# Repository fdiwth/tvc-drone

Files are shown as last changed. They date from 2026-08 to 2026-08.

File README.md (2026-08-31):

# About

<div align="center">
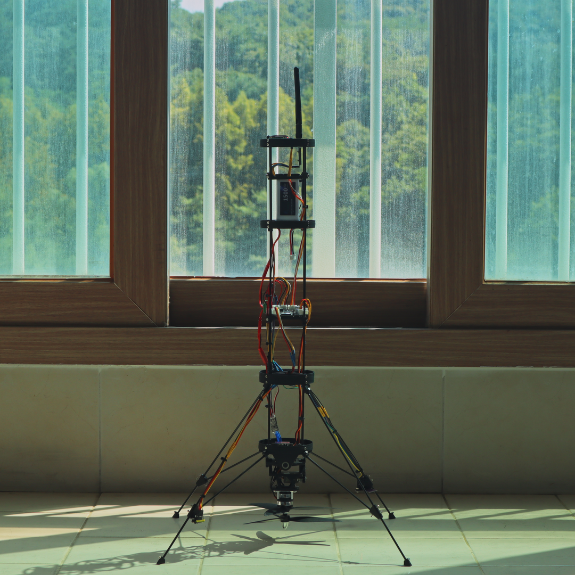
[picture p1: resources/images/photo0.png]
	
</div>

The TVC(Thrust Vector Control) drone project is a demonstration of the control capabilities that can be achieved in amateur rocketry. Similar to an actual rocket with a TVC system, the drone is capable of balancing and angling itself at desired a desired set-point by vectoring the thrust it produces appropriately. This repository contains the documentation of the project along with sources of both hardware and software that was developed in the duration of the project.

# Navigating the Repository

The repository is mainly split into five sections:

 - tvc-drone/apps
 - tvc-drone/docs
 - tvc-drone/gcs-firmware
 - tvc-drone/drone-firmware
 - tvc-drone/resources

The best way to navigate this repository if you are looking for an in depth guide is to follow along the documentation available in your language of choice below tvc-drone/docs. The documentation explains the design choices, and the links to appropriate sections of the repository.

If you are looking to look at a specific part of the sources, navigating to the appropriately named folders will help find the resources you need.

To get a short overview of the features used in the project, check out the overview section available at tvc-drone/docs/{language}.

# Videos

Click on the images of videos to watch them. Watch video 5 or 6 if you want to see the result.

<div align="center">
	<a href="https://www.instagram.com/reel/DbS7qK0ilDo/?utm_source=ig_web_copy_link&igsi=MzRlODBiNWFlZA==" target="_blank" rel="noopener noreferrer"> 
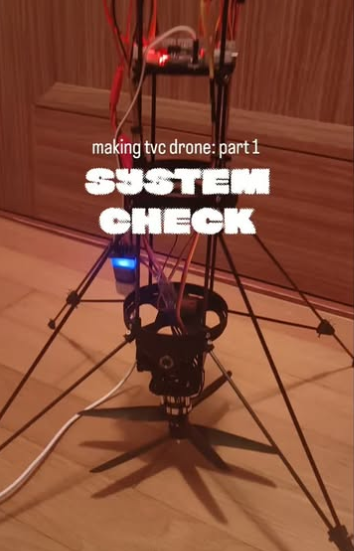
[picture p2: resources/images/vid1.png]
		
	</a>
	<a href="https://www.instagram.com/reel/DbS74EgiR94/?utm_source=ig_web_copy_link&igsi=MzRlODBiNWFlZA==" target="_blank" rel="noopener noreferrer"> 
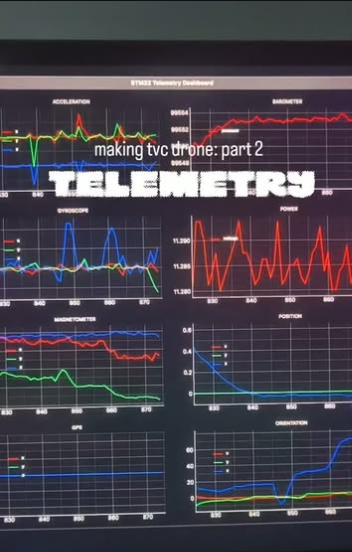
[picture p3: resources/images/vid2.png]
		
	</a>
	<a href="https://www.instagram.com/reel/DbS8F_3iFV1/?utm_source=ig_web_copy_link&igsi=MzRlODBiNWFlZA==" target="_blank" rel="noopener noreferrer"> 
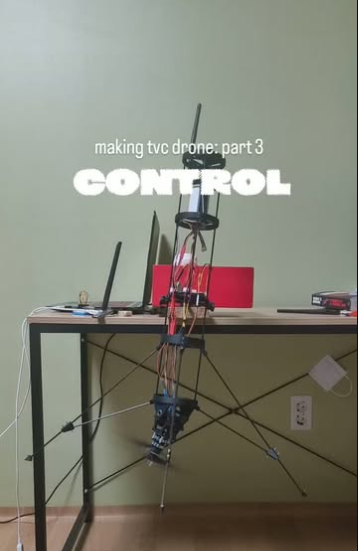
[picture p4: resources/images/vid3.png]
		
	</a>
	<a href="https://www.instagram.com/reel/DbS8Rr6iW9l/?utm_source=ig_web_copy_link&igsi=MzRlODBiNWFlZA==" target="_blank" rel="noopener noreferrer"> 
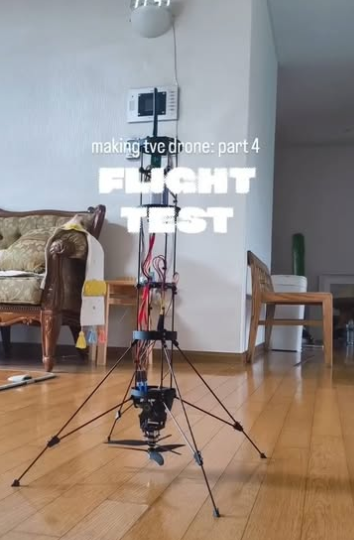
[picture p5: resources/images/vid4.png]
		
	</a>
	<a href="https://www.instagram.com/reel/Db1qBOZSPOG/?utm_source=ig_web_copy_link&igsi=MzRlODBiNWFlZA==" target="_blank" rel="noopener noreferrer"> 
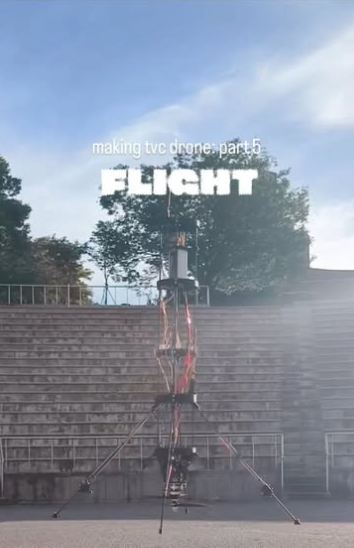
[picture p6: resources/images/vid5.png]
		
	</a>
	<a href="https://www.instagram.com/reel/Db5uuldi-zH/?utm_source=ig_web_copy_link&igsi=MzRlODBiNWFlZA==" target="_blank" rel="noopener noreferrer"> 
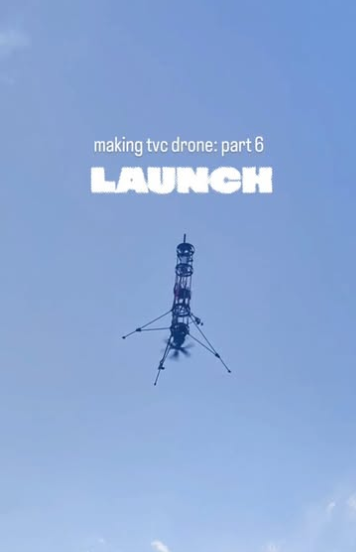
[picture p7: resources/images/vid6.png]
		
	</a>
</div>

# Disclaimer

This repository is merely a demonstration of what is achievable with a custom-built coaxial TVC drone stack, and is not a step-by-step guide on building one. Despite the project materials being open sourced, it is discouraged to use them directly in one's own project. However, anyone is welcome to use the documentations and source materials as a reference. But treat this as a reference point, not a direct dependency. 

# Contact

Anyone with any questions regarding this project are welcome to reach out through contact informations listed below.

instagram: fd.iwth
email: fdiwth@gmail.com

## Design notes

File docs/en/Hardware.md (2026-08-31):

# Index

1. [Design](#design)
	  - [Hardware Specifications](#hardware-specifications)
	  - [Coaxial Design](#coaxial-design)
	  - [Gimbal Design](#gimbal-design)
	  - [Body Design](#body-design)
	  - [Sensor Placement and Configuration](#sensor-placement-and-configuration)
2. [PCB](#pcb)
	  - [Component Overview](#component-overview)
	  - [System Initialization and Checks](#system-initialization-and-checks)
	  - [Microcontroller and Sensors](#microcontroller-and-sensors)
	  - [Data Logging Architecture](#data-logging-architecture)
	  - [Power System](#power-system)
	  - [Custom Sensor Modules](#custom-sensor-modules)
	  - [Power Delivery System](#power-delivery-system)

# Design

This section explains the hardware design of the drone along with why it was designed that way. Key hardware components and major design choices were made during the process of building, and each of them will be explained in the following sub-sections.

1. Hardware Specifications
2. Coaxial Design
3. Gimbal Design
4. Body Design

### **Hardware Specifications**

The drone uses the following core hardware components to achieve flight:
- **Motors**: DZP30 counter-rotating motors (KV: 1500, Thrust: ~280g each, Current: 0.5A at 11.1V).
- **ESCs**: XP-12A (12A rating, with BEC).
- **Propellers**: 7035 (7-inch diameter, 3.5-inch pitch, 3-blade, 5mm inner hole).
- **Battery**: 3S 1500mAh 45C LiPo with JST connector.

### **Coaxial Design**

Unlike a traditional rocket engine that doesn't produce any significant amount of z-axis torque, using a spinning motor with propellers introduces z-axis torque. The z-axis rotational dynamics are governed by two factors. A major dynamic at hand which is constantly present when the motors are spinning is the torque that is applied in the opposite direction of the spinning motor. This dynamic would not be present in a complete vacuum when the motor is not being either accelerated. Since there is no change in angular momentum without acceleration, there is effectively zero torque. However, in the real world, propellers attached to the motors create thrust by accelerating the air molecules which, according to Newton's third law of motion induces force in the opposite direction. This has the effect of decelerating the motors. In order to maintain a constant angular velocity, the motors need to accelerate, thus creating an equal and opposite torque on the body even when the motors are maintaining their angular velocity. Second, another dynamic at hand is the conservation of angular momentum. This can be seen when the motor accelerates by increasing/decreasing its angular velocity. 

For a drone to achieve stability it needs to be able to control it's z-axis. This is the reason for choosing the coaxial design. Having two motors rotating in the opposite direction allows the torque to cancel each other. In an ideal scenario, where both motors spin at the same angular velocity and produce equal amount of thrust(each of them producing 1/2 of total thrust) torques produced should have the same magnitude and be directed at opposite directions, making the net torque 0. However, real world is far from the ideal case. since two propellers are stacked on top of each other airflow from top propellers create iregullarties from the ideal scenario. Thus, we need to be able to control the angular velocity of each counter rotating motors individually. By accelerating one motor and decellerating the other appropriately, this system is capable of producing the same amount of thrust while creating a torque in the desired direction.

### **Gimbal Design**

The gimbal uses two cheap and widely available MG90S servos. Metal gear servos were particularly chosen because they have far less backlash than soft geared servos. The specific model was chosen because of its cheap price. 3D printed gears were used on both axis to reduce the amount of torque each motor has to generate and to allow the gimbal control to be more precise. However, the use of gears resulted in its own backlash problem, which had to be reduced by iteratively testing different gear diameters. 

In the design, one of the gears have a normal 3:1 reduction ratio, and the other has a 4:1 gear reduction ratio. This is due to the geometry of how the servos are mounted. Servo-x is operated like a normal gear with a gear ratio of 3:1 and has a fixed spinning axis, as shown in section analysis below.

<div align="center">
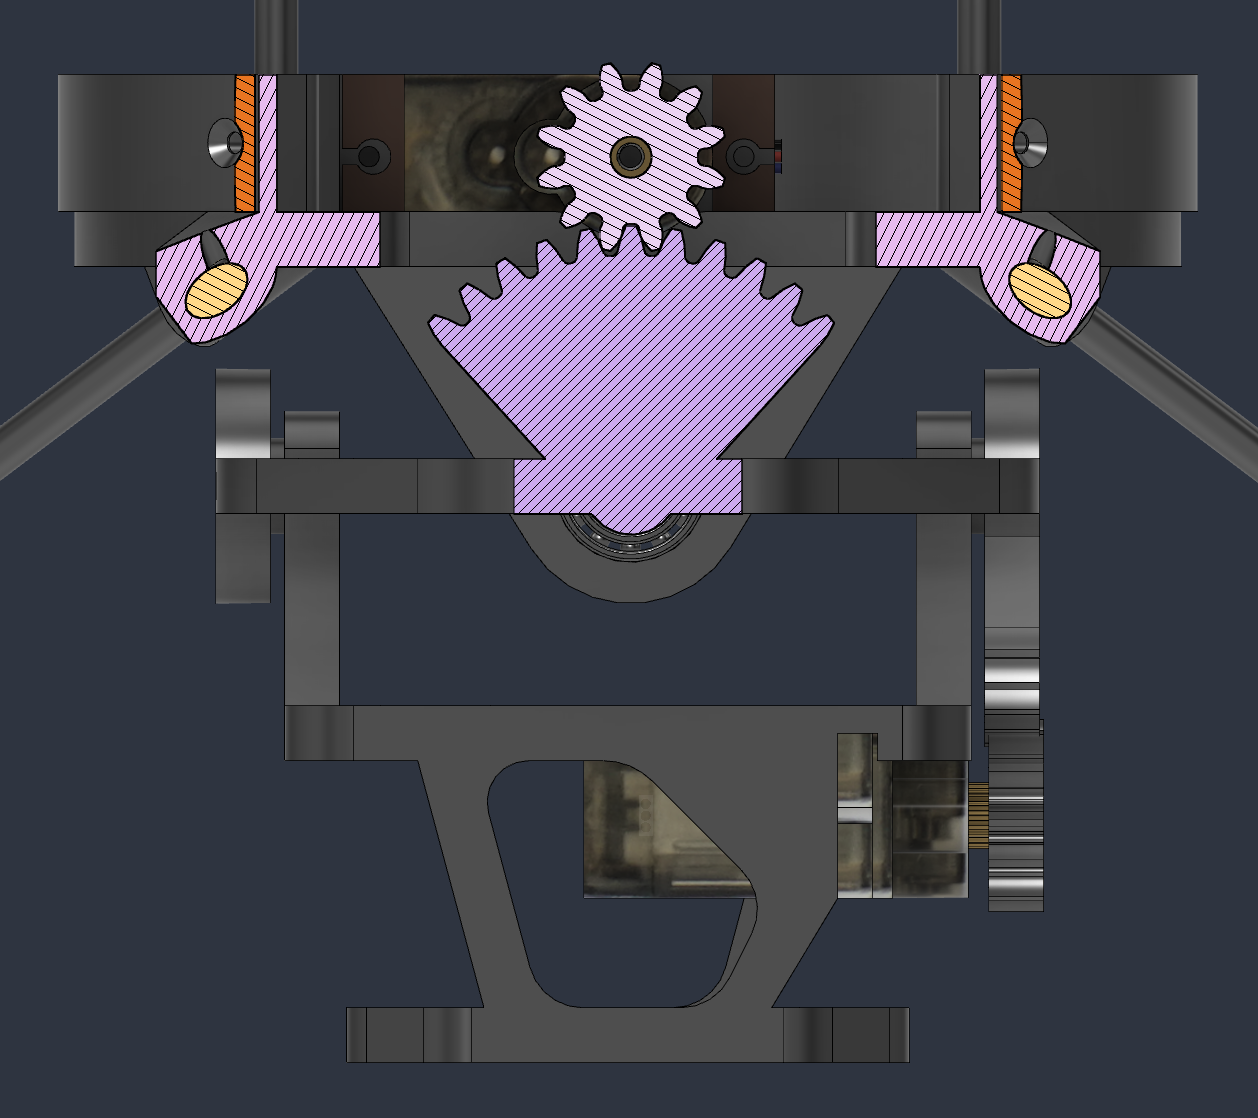
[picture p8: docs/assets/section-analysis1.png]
	
</div>

However, the gear attached to the servo-y revolves around the TVC axis as it rotates. This rotation of the axis makes it necessary for the servo to make an additional full rotation when TVC is rotated 360 degrees making the gear ratio 4:1. This effect has to be accounted for when managing TVC angles in software.

<div align="center">
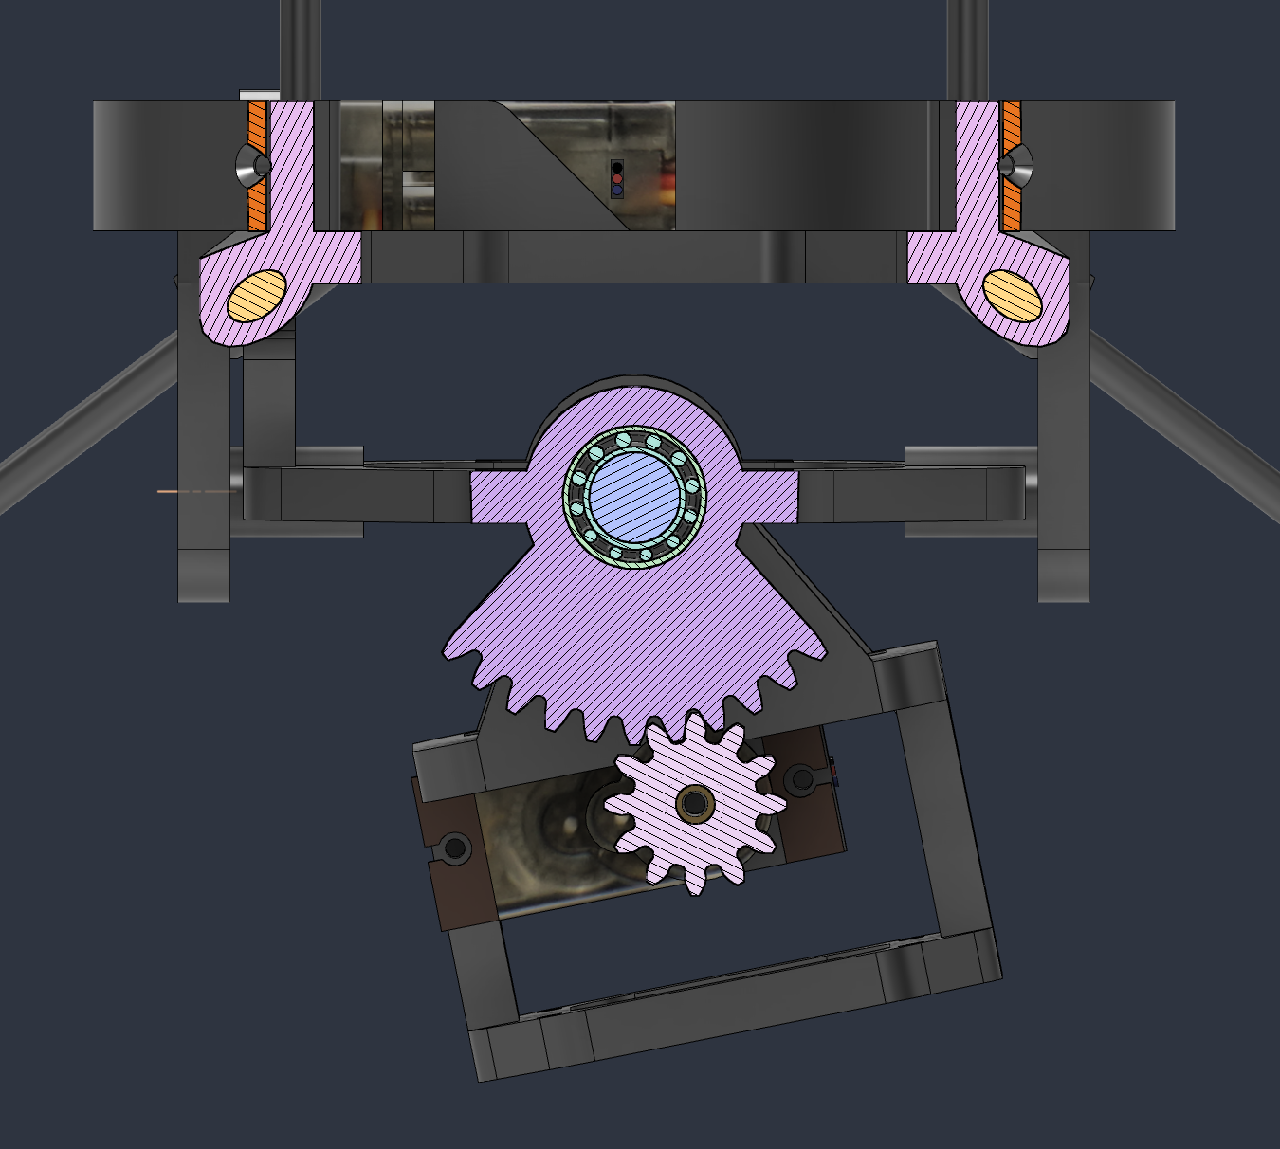
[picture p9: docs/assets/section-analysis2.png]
	
</div>

### **Body Design**

The body frame ware structured using 3mm solid carbon fiber rods cut to appropriate lengths to make the drone light weight and rigid. The rods are held together by custom designed 3D printed pieces. The rods are held to the 3D printed part by screws that was screwed into place by making the diameter of the hole in the 3D printed part slightly smaller than screw size. A small indent was made on the rod in the position of the screw, so that the indent would hold the rod in place.

The body was made to be long, and most of the mass(including the battery, motors, radio antenna) were located far from the center of mass intentionally! Since the moment of inertia is equivalent to 

$$I = \sum_{i=1}^{n} m_i r_i^2$$

where $r_i$ is the distance of small mass $m_i$ from the center of gravity, distributing the components with mass increases the moment of inertia of an object. Increased moment of inertia makes the tipping of the drone slower, since by definition moment of inertia is the resistance to change in angular velocity.

Other reasons for this design choice can be seen clearly with a simple example of the same 2D system with a proportional controller. Imagine a system that responds to an error by tilting the tvc gimbal proportionally to $\theta$(the error from desired angle of 0).

For small tvc deflection angle $\phi$,

$$ \tau = -F_t \cdot d \cdot \sin(\phi) \approx F_t \cdot d \cdot \phi$$
$$ I_{cg} \ddot \theta = -F_t \cdot d \cdot \phi$$

Since we are modeling a proportional controller,

$$\phi = K_p \theta$$
$$ I_{cg} \ddot \theta = -F_t \cdot d \cdot K_p \theta$$
$$  \ddot \theta + \frac {F_t \cdot d \cdot K_p}{I_{cg}} \theta = 0$$

This is similar to the equation of undamped harmonic oscillator which is written as
$\ddot x + \omega_n^2 x = 0$ where $\omega$ is the natural frequency of the system.

Thus, the closed loop natural frequency of this system can be expressed as

$$\omega_n = \sqrt{\frac {F_t \cdot d \cdot K_p}{I_{cg}}}$$

From this model, we can see that the closed-loop natural frequency increases as $I_{cg}$ decreases. A small $I_{cg}$ leads to rapid, high-frequency oscillations around the target angle. This is highly problematic for a real-world TVC drone because physical hardware constraints-such as a 50Hz servo refresh rate and non-zero servo transit time-are omitted from the ideal model. High frequencies paired with servo lag induce a catastrophic phase shift, leading to instability. By increasing $I_{cg}$, we effectively shift control authority from the chaotic, high-frequency raw rotational dynamics of a light airframe over to a tunable software parameter $K_{p}$. The enlarged $I_{cg}$ suppresses the natural frequency ceiling, allowing $K_{p}$ to be aggressively increased to reject wind disturbances heavily without forcing the servos past their physical bandwidth limitations.

### **Sensor Placement and Configuration**

Proper sensor placement and configuration are critical for accurate state estimation, particularly for sensors interacting directly with the ground.

- **IMU (ICM-42688-P)**: Configured in `main.c` for $\pm8$G acceleration and $\pm500$ degrees/sec, sampling at 1760Hz to minimize phase delay before filtering.
- **Barometer (BMP388)**: Configured to sample at 50Hz with 8$\times$ oversampling for pressure, balancing noise reduction with responsiveness.
- **Time of Flight (ToF) Sensor (VL53L1X)**: Placed facing directly downwards at one of the legs of the drone to measure altitude. The sensor is theoretically capable of measuring up to 4 meters, which perfectly aligns with the crucial low-altitude landing and hovering phases. 
- **Optical Flow Sensor (PMW3901)**: Mounted on one of the drone's outer legs located opposite of the leg ToF sensor is mounted to, due to space constraints and line-of-sight requirements. Because the leg mounts are angled, the sensor's native X and Y axes sit at a 45-degree angle relative to the flight controller's primary coordinate frame. To resolve this, the firmware mathematically rotates the raw PMW3901 readings by 45 degrees before fusing them into the velocity estimators.

# PCB

This section explains the architectural and hardware design choices behind the flight controller PCB, focusing on component selection and power delivery.

The PCB was designed using KiCAD, an open-source electronics design automation suite. The selection of components was crucial, as it dictates the capabilities, stability, and future extensibility of the TVC drone.

### **Component Overview**

| Type | Model | Interface | Purpose |
| --- | --- | --- | --- |
| MCU | STM32F722RET | SWD | Main flight controller processor |
| IMU | ICM-42688-P | SPI | 6-axis gyroscope and accelerometer |
| Magnetometer | BMM150 | I2C | Z-axis rotation and absolute heading |
| Barometer | BMP388 | SPI | Altitude and temperature sensing |
| GPS | U-blox NEO-7 | UART/Custom | Global Positioning System |
| Power Sensor | INA226 | I2C | Battery voltage and current monitoring  |
| Flash Memory | W25Q128JVSIQ | SPI | 16MB onboard flight data logging |
| SD card | TF-01A | SDMMC | Removable post-flight data storage |
| USB OTG | USB4105-GF-A-120 | USB-C | Debugging and data extraction |
| Power Mux | TPS2121 | - | Intelligent battery/USB power switching |
| Buzzer | MLT-8540 | GPIO | Audiovisual feedback |

### **System Initialization and Checks**

During boot, the flight controller executes `sys_init()` function to initialize the system. The function initializes all the components of the drone and tries to establish a connection with the GCS(Ground Control Station). 

A `sys_check()` function can also be run afterwards by sending "CHECK" command from the GCS. This ensures all sensors and components are functioning correctly before launch. The function includes:

1. **Audiovisual Feedback**: Testing the Buzzer and LEDs.
2. **Actuator Sweeps**: Commanding the X and Y servos, followed by the main motors, through a limited sweep to confirm ESC and servo responses.
3. **Sensor Polling**: Verifying the IMU (ICM-42688-P), Magnetometer (BMM150), Barometer (BMP388), and Power Sensor (INA226) are successfully responding to SPI/I2C DMA requests.
4. **Memory Verification**: Erasing and writing a test sector on the W25Q128 flash memory, and writing a mock CSV file to the SD card to ensure data logging will not fail mid-flight.

### **Microcontroller and Sensors**

The **MCU (Microcontroller Unit)** is responsible for running the attitude control loops, reading sensor data, and commanding the servos and motors. The STM32F722RET was chosen for its compact size, high clock speed, and rich set of hardware peripherals (SPI, I2C, SDMMC).

The **IMU (Inertial Measurement Unit)** provides the foundational gyroscope and accelerometer readings necessary for attitude stabilization. While the IMU accurately tracks X and Y axis rotations (pitch and roll), it cannot determine absolute Z-axis orientation (yaw) without drift. Therefore, a **Magnetometer (BMM150)** is included to sense the Earth's magnetic field and provide drift-free yaw measurements.

A **Barometer (BMP388)** is also included to detect minute changes in air pressure, allowing the flight controller to estimate the drone's altitude. 

### **Data Logging Architecture**

For debugging and performance tuning, a robust logging system is critical. The PCB utilizes a two-stage logging approach to handle high-speed data:

1.  **In-Flight (High Speed)**: During flight, sensor data and control variables are logged via SPI to the onboard **W25Q128JVSIQ 16MB Flash Memory**. Writing directly to a physical SD card during flight is avoided because mechanical vibrations can cause brief disconnections, leading to fatal latency spikes or corrupted files. The flash memory uses a **Variable-Field Bitmask Serialization** format to tightly pack only necessary fields into 256-byte pages, maximizing the 16MB capacity.
2.  **Post-Flight (Data Extraction)**: After the flight controller receives a "KILL" command (disarming the vehicle), the logged binary data is automatically dumped from the flash memory into the **MicroSD card**, converting it into a readable CSV format (`flight.csv`). This method guarantees data integrity while providing an easily accessible file for ground station analysis. This approach was heavily inspired by the designs of flight controllers from BPS.Space.

### **Power System**

Power distribution is essential for stable flight, especially when multiple high-current servos and motors share the same supply as sensitive I2C sensors.

- The INA226 power sensor is explicitly configured for ultra-fast 140µs voltage conversion times. This guarantees that battery voltage telemetry does not bottleneck the strict 100Hz real-time attitude control loop.
- A 3.3V Step-Down Converter is used to efficiently step down the 3S LiPo battery voltage for the logic components.
- The main battery directly drives the ESCs and servos, removing massive current spikes from the logic rails.

### **Custom Sensor Modules**

The PMW3901 (Optical Flow) and VL53L1X (Time of Flight) sensors are used as modules rather than as embedded sensors in the main flight controller PCB.
- This allows optimal downward-facing placement, minimizing interference from the drone's frame or propellers.
- The flexibility means if a crash damages a sensor leg, I only have to replace the small module rather than the entire flight controller stack.
- **DMA and Semaphore Safety**: Because these sensors communicate over external wires, they are susceptible to electrical noise or disconnects mid-flight. To prevent a dead I2C/SPI bus from hanging the CPU and crashing the drone, all sensor polling is offloaded to hardware DMA channels, wrapped in FreeRTOS Mutexes, and bound by OS-level timeouts.

### **Power Delivery System**

The power route follows the path: +BATT -> motors -> +5V -> servos -> +3.3V -> STM32 & sensors.

Unlike standard quadcopters that rely on the limited Battery Elimination Circuit (BEC) from an ESC to power the flight controller, this TVC drone requires significant current for the 2 onboard servos, which needs to be constantly actuated during flight. To address this, the PCB is powered directly from the 3S LiPo battery via screw terminals and steps down the voltage onboard:

*   **Buck Converter (MP2393)**: Drops the +11.1V (3S LiPo) to a stable +5V to power the MG90S servos. The MP2393 was selected for its high efficiency under significant current draw. The Power Good (PG) pin is routed to an STM32 GPIO for power status monitoring (currently not in use).

*   **Linear Regulator (AMS1117-3.3)**: Steps down the +5V rail to an clean +3.3V to power the STM32 MCU and sensitive I2C/SPI sensors.

### **Dual-Power USB Switching**

The flight controller can be powered by either the LiPo battery or the USB-C connection during bench testing. To prevent dangerous back-driving of voltage into the USB port while the battery is connected, a **TPS2121 Power Multiplexer** is used. It is configured to automatically prioritize the battery input (IN1) as long as it remains above 3.3V, providing seamless power switching and VBUS protection. An **INA226** IC is also placed in line to monitor the battery's voltage and current draw, enabling dynamic ESC throttle compensation as the battery drains.

Additionally, to protect the USB connection from Electrostatic Discharge (ESD), the datalines are guarded using **USBLC6-2SC6**, and the VBUS line is protected via **ESDA7P60-1U1M**. A VBUS sensing circuit allows the MCU to only attempt USB communication when genuinely connected.

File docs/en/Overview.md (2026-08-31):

# Index

1. [Motive](#motive)
2. [Conventions](#conventions)
3. [System](#system)
4. [Control](#control)
5. [Tuning](#tuning)
6. [Features](#features)

# Motive

The drone was made to resemble the dynamics of a rocket in that it produces thrust below the center of mass. However, this design is inherently unstable, and even a small initial tilt will result to the rocket tipping over. An actual rocket overcomes this with mainly two strategies:

1. having the center of pressure lower than the center of gravity at high speeds
2. using a system to actively control the orientation of the rocket

Since the first method can only apply when the rocket moving through the air in the supposed forward direction, it is critical for rockets during the launch or a landing to have a mechanism for stabilizing it.
Once of the most common control mechanisms used is the TVC(Thrust Vector Control). Explained simply, it is a method of stabilizing the rocket by vectoring(changing the direction of thrust). This project focuses on achieving controlled flight using the TVC technology in making a VTVL(Vertical Takeoff Vertical Landing) drone, as a test for the robustness of the TVC control system.
Most of the resources used in this project including 3D CAD models, flight controller PCB, communication protocols, software, was built from scratch to allow full control of the drone's system to the maker.

# Conventions

The drone's coordinate system is shown in the diagram below, along with its associated angles. Roll(x-axis rotation), pitch(y-axis rotation), yaw(z-axis rotation) is used through out the documentation.

# System

The system consists of two havlves:

1. The Drone: Powered by an STM32F722RET microcontroller with dedicated timer triggered FreeRTOS. It is responsible for all time-critical sensor fusion, stabilization, data logging, and actuator commanding.
2. The Ground Control Station(GCS): Powered by an ESP32 microcontroller that interfaces with physical joysticks and a host PC. It manages telemetry decoding, flight mode switching, and relaying operator commands over long-range LoRa RF.

# Control

To achieve stabilization and controlled flight despite the inherently unstable nature of a thrust-vectored vehicle, the flight controller employs a cascading three-level control loop:

1. Position (Outer Loop - P Controller): Looks at the desired 3D coordinates in space and calculates the necessary target velocities to get there.
2. Velocity (Middle Loop - PID Controller): Looks at the target velocities and computes the necessary vehicle tilt (target roll and pitch angles) to accelerate the drone in the correct direction.
3. Attitude (Inner Loop - LQR Controller): Takes the target orientation angles and computes the optimal rapid actuator commands (servo angles and motor thrusts) needed to physically orient the drone without overshooting.

# Tuning

While the LQR controller can calculate mathematically perfect corrections, the physical servos are bound by finite transit times and a 50Hz PWM refresh rate. If the software requests high-frequency oscillations that the servos cannot physically track, it induces a phase lag, leading to catastrophic instability. Thus, the control philosophy heavily relies on constraining the software (clamping max velocity, limiting P-gains, filtering D-terms) to respect the physical bandwidth limits of the hardware.

# Features
Based on the project goals, the following requirements were met in the design:

* Radio communication via LoRa
* Capable of vertical takeoff and landing (VTVL)
* Onboard flash memory and Micro SD for data logging
* Control of 2 counter-rotating motors and 4 gimbal servos
* STM32-based flight controller
* Audiovisual feedback (Buzzer and LEDs)
* External pins for VCC & GND and additional sensors
* Battery voltage and current monitoring
* USB-C interface for debugging and dual-power switching
* Sensor suite: Magnetometer, Accelerometer, Gyroscope, Barometer (Temperature/Pressure)

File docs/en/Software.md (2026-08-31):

# Index

1. [Controls](#controls)
	- [LQR](#lqr)
	- [PID](#pid)
	- [Anti-Windup Mechanisms](#anti-windup-mechanisms)
	- [LQR Servo Mapping](#lqr-servo-mapping)
2. [Sensor fusion](#sensor-fusion)
	  - [Orientation Fusion](#orientation-fusion)
	  - [Altitude Fusion](#altitude-fusion)
	  - [Velocity Fusion](#velocity-fusion)
	  - [Low-pass Filter](#low-pass-filter)
	  - [Sensor Calibration](#sensor-calibration)
3. [Communication](#communication)
	  - [LoRa Configuration](#lora-configuration)
	  - [Asymmetric Communication Protocol](#asymmetric-communication-protocol)
	  - [Packet Structure](#packet-structure)
4. [FreeRTOS](#freertos)
	  - [Flight State](#flight-state)

# Controls

There are mainly four different ways to make a TVC system: movable fins, gimbaled thrust, vernier rocket, and thrust vanes.

<div align="center">
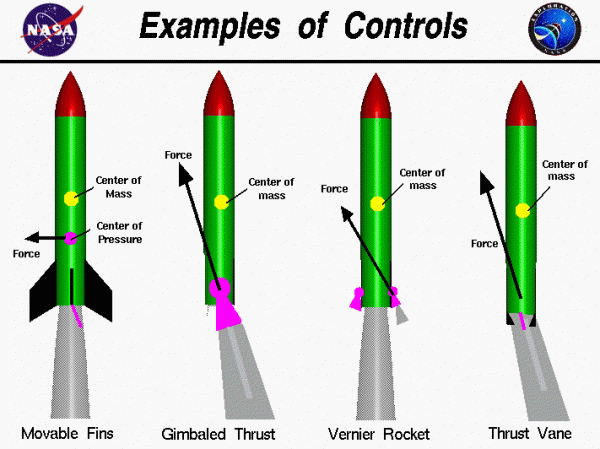
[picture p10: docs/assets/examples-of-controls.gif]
	
</div>

However, the most modern rockets like SpaceX's falcon 9 and Starship, Rocket Lab's Electron, NASA's SLS,  KARI's Nuri(KSLV-II), JAXA's H3, CASC's Long March, ESA's Ariane and so on use gimbaled thrust to achieve controllability during flight. 

Overall, the controllable values of the drone are the pwm signals for servo-x, servo-y, motor1, and motor2. With these, the drone is able to control its orientation and position around all x, y and z axis. 
### **LQR**

A control scheme used in controlling the orientation and altitude of the drone is the **LQR (Linear Quadratic Regulator)**. This uses state vectors reflecting the current state of the system and matrices that are pre-computed using the properties of the system to drive the actuators in the direction that minimizes error. Because the gain matrix is pre-computed to be optimal, it bypasses the tedious process of manual tuning and only requires bench tests to balance the gains for different types of error and actuation penalty.

The controller operates on a 12-state augmented vector consisting of orientation/altitude errors, their derivatives, and their integrals:

$$
\mathbf{x} = \begin{bmatrix} r_x & r_y & r_z & p_z & \dot{r}_x & \dot{r}_y & \dot{r}_z & \dot{p}_z & \int r_x & \int r_y & \int r_z & \int p_z \end{bmatrix}^T \in \mathbb{R}^{12}
$$

where $r_x, r_y, r_z$ are roll/pitch/yaw orientation errors, $p_z$ is the altitude (position-z) error, the $\dot{(\cdot)}$ terms are their rates, and the $\int(\cdot)$ terms are their accumulated integrals, which are added for steady-state error rejection.

The system is modeled as a linear time-invariant plant:

$$
\dot{\mathbf{x}} = A_c \mathbf{x} + B_c \mathbf{u}
$$

with the state matrix $A_c$ encoding the kinematic relationships:

$$
A_c =
\left[\begin{array}{cccccccccccc}
0&0&0&0&1&0&0&0&0&0&0&0\\
0&0&0&0&0&1&0&0&0&0&0&0\\
0&0&0&0&0&0&1&0&0&0&0&0\\
0&0&0&0&0&0&0&1&0&0&0&0\\
0&0&0&0&0&0&0&0&0&0&0&0\\
0&0&0&0&0&0&0&0&0&0&0&0\\
0&0&0&0&0&0&0&0&0&0&0&0\\
0&0&0&0&0&0&0&0&0&0&0&0\\
1&0&0&0&0&0&0&0&0&0&0&0\\
0&1&0&0&0&0&0&0&0&0&0&0\\
0&0&1&0&0&0&0&0&0&0&0&0\\
0&0&0&1&0&0&0&0&0&0&0&0
\end{array}\right]
$$

and the input matrix $B_c$ mapping the actuation vector $\mathbf{u} = \begin{bmatrix} u_0 & u_1 & u_2 & u_3 \end{bmatrix}^T$ (servo-x, servo-y, differential thrust, main thrust) into the rate states, scaled by the physical control-effectiveness constants $B_{rx}$, $B_{ry}$, $B_{rz}$, $B_{pz}$. Values for $B_{rx}$ and $B_{ry}$ were determined using bifilar pendulum to calculate moment of inertia about the CG at x and y axis, $B_{rz}$ was determined empirically by testing the angular acceleration about the z axis at various rpm differences of motors. Lastly, $B_{pz}$ was simply calculated using the drone's final mass.

$$
B_c =
\left[\begin{array}{cccc}
0&0&0&0\\
0&0&0&0\\
0&0&0&0\\
0&0&0&0\\
-B_{rx}&0&0&0\\
0&B_{ry}&0&0\\
0&0&B_{rz}&0\\
0&0&0&B_{pz}\\
0&0&0&0\\
0&0&0&0\\
0&0&0&0\\
0&0&0&0
\end{array}\right]
$$

Since the flight controller runs at a fixed control-loop rate, the continuous plant is converted to discrete time via zero-order hold with sample time $\Delta t$:

$$
\mathbf{x}_{k+1} = A_d \mathbf{x}_k + B_d \mathbf{u}_k, \qquad (A_d, B_d) = \mathrm{ZOH}(A_c, B_c, \Delta t)
$$

The LQR gain is found by minimizing the infinite-horizon quadratic cost:

$$
J = \sum_{k=0}^{\infty} \left( \mathbf{x}_k^T Q \, \mathbf{x}_k + \mathbf{u}_k^T R \, \mathbf{u}_k \right)
$$

where $Q \in \mathbb{R}^{12\times12}$ penalizes state error (orientation, rate, and integral terms) and $R \in \mathbb{R}^{4\times4}$ penalizes actuator effort:

$$
Q = \text{diag}\big(q_{r_x},\, q_{r_y},\, q_{r_z},\, q_{p_z},\, q_{\dot r_x},\, q_{\dot r_y},\, q_{\dot r_z},\, q_{\dot p_z},\, q_{\int r_x},\, q_{\int r_y},\, q_{\int r_z},\, q_{\int p_z}\big)
$$

$$
R = \text{diag}\big(r_{u_0},\, r_{u_1},\, r_{u_2},\, r_{u_3}\big)
$$

The optimal cost-to-go matrix $P$ is obtained by solving the DARE:

$$
P = A_d^T P A_d - A_d^T P B_d \left( R + B_d^T P B_d \right)^{-1} B_d^T P A_d + Q
$$

This can be solved by using either python(`lqr_compute.py`) or matlab (`lqr_compute.m`)

The optimal feedback gain matrix is then computed directly from $P$:

$$
K = \left( R + B_d^T P B_d \right)^{-1} B_d^T P A_d
$$

and the control input applied at each time step is the linear feedback law:

$$
\mathbf{u}_k = -K \, \mathbf{x}_k
$$

Because $K$ is solved once for the full 12-state augmented system, the resulting gains for the servo, differential-thrust, and thrust-vectoring channels are already balanced against one another. This eliminates the need for manual PID-style tuning and leaving only bench testing to fine-tune the relative weighting between error suppression and actuation cost. 
### **PID**

Most drone use the PID(Proportional Integral Derivative) controlling scheme to maintain stability during flight. Where the control output regarding the error is actuated in a tuned factor to each of proportional, integral and derivative gains. The proportional term steers the system towards reducing the error, the integral term accounts for inaccuracies in the system, and finally the derivative term acts as a damping to the otherwise oscillating system. Here is a great video on it: https://youtu.be/4Y7zG48uHRo?si=Jpp3Fp_0xEZwwcJJ.

$$u(t) = K_p e(t) + K_i \int_{0}^{t} e(\tau) \, d\tau + K_d \frac{d e(t)}{dt}$$

Because the integral and derivative has to be calculated computationally in a discrete time the function becomes:

$$u(t_n) = K_p e(t_n) + K_i \sum_{k=0}^{n} e(t_k) \Delta t + K_d \frac{e(t_n) - e(t_{n-1})}{\Delta t}$$

The XY (horizontal) position was controlled using a **cascaded structure**. In this cascaded structure, the target XY orientation is decided by a PID controller regulating XY velocity. The target XY velocity, in turn, is decided by a P controller regulating XY position errors.

1. Position Error  Target Velocity (P Controller): The outermost loop calculates the difference between the desired target coordinate and the current 3D position. A simple proportional (P) controller converts this distance error into a target velocity. This prevents the drone from attempting to instantly teleport to the target, instead moving at a controlled speed.
   - Tuning ($K_p$ = 0.5): The firmware utilizes a highly conservative gain of $0.5$ for both the X and Y axes.
   - Clamping: The output of this stage is strictly clamped to $\pm0.5$ m/s to prevent erratic, high-speed lunges during large position changes.

1. Velocity Error $\rightarrow$ Target Attitude (PID Controller): The middle loop compares the current estimated velocity (from the Optical Flow and IMU fusion) against the target velocity provided by the Position loop. It uses a full Proportional-Integral-Derivative (PID) controller to output a target roll/pitch angle. To accelerate forward, the drone must pitch forward.
   - Tuning ($K_p$ = 0.140, $K_i$ = 0.040, $K_d$ = 0.008): Notice that the gains here are much smaller than the outer loop.
   - Clamping: The target attitude output is hard-clamped to $\pm0.2$ radians ($\approx 11.4^\circ$). This hard limit prevents the drone from ever commanding an extreme tilt that could compromise lift or cause an unrecoverable flip.

<div align="center">
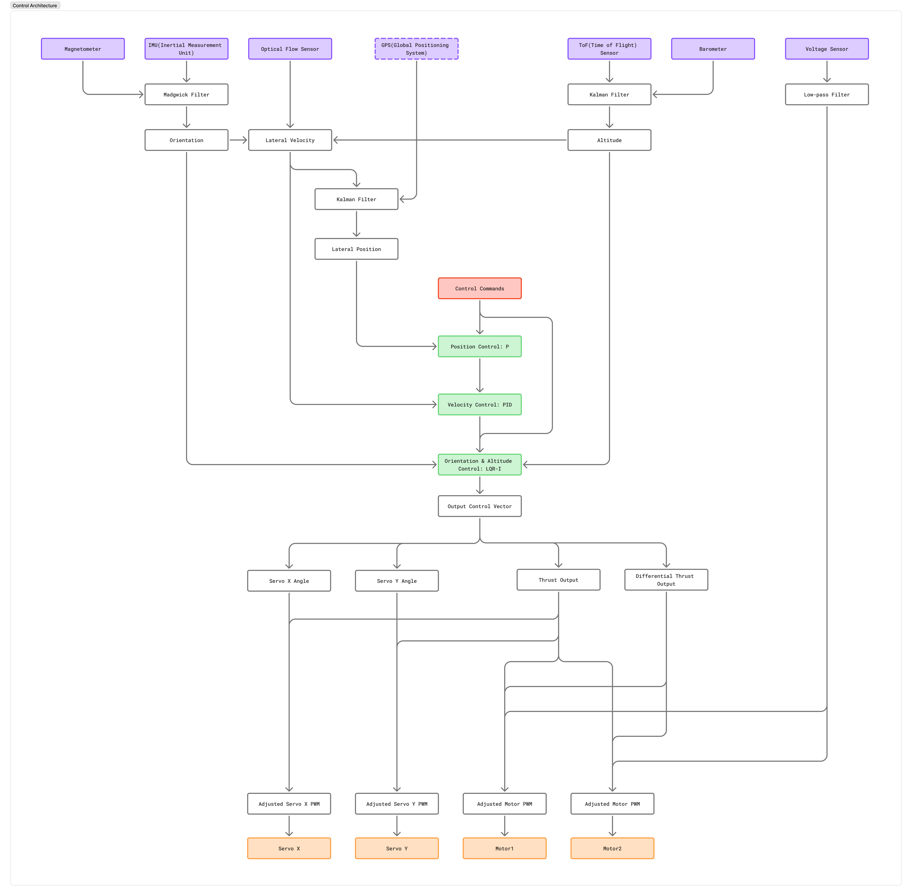
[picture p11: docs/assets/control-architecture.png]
	
</div>

The position control is essential if one wants to prevent drift of the drone. Because the drone produces thrust below its center of gravity, it is dynamically similar to an inverted pendulum. It is inherently unstable and wants to tip over. Furthermore, tilting the gimbal in one direction not only causes a rotational torque but also induces translational motion. If there are slight misalignments in the CG or servos, the system will slowly drift over time. 

As mentioned, the XY controller is split into an inner PID controller for velocity and an outer P controller for position. This structure allows the inner controller to quickly absorb any systematic mechanical offsets with its Integral (I) gain, while allowing the Proportional (P) gain of the outer position loop to be adjusted independently.
### **Anti-Windup Mechanisms**

Because the control architecture is cascaded (Position $\rightarrow$ Velocity $\rightarrow$ Attitude), a crucial issue arises: integral windup. If the drone is pushed hard and the servos reach their physical maximum angle (saturation), the position and velocity errors will continue to grow because the drone cannot physically tilt any further to correct it. Without safeguards, the Integral term in the velocity loop would accumulate a massive, unrealistic error value. Once the drone is released, this huge integral value would cause the drone to violently snap back in the opposite direction.

To solve this, the firmware implements an intelligent **Anti-Windup mechanism** in `freertos.c`. The system continuously monitors the downstream outputs (servo angles and motor thrusts). If the LQR attitude controller reaches its maximum allowed limits, a signal is passed back up the chain to the velocity PID controllers to *freeze* their integral accumulators. The integrals are only allowed to grow when the system has the physical authority to act upon them.
### **LQR Servo Mapping**

The LQR output vector ($u$) produces normalized control efforts. These values cannot be written directly to the hardware. Instead, they are translated into specific PWM signals for the two gimbal servos and two brushless motors through a mixing matrix.
- Base Offset (`LQR_SSO = 50`): The neutral, upright position for the servos is defined as an percentage of 50% of actuation range. The LQR pitch and roll efforts are scaled and dynamically added/subtracted from this base offset.
- Differential Thrust: Because the drone lacks a physical yaw servo, the LQR yaw effort ($u_2$) is mapped to a thrust differential. A positive yaw command adds thrust to Motor 1 while equally subtracting it from Motor 2, generating a rotational torque without affecting the total altitude lift.
# Sensor fusion

The most important part of a controls system is the sensors. If a system has no idea on what state it is at, it does not have the ability to steer itself towards the targeted state. First, the drone needs to know how it is oriented and second, it needs to know where it's positioned at. There are many sensors aboard the PCB and there are other sensors that are connected to the PCB via connectors that allow the drone to function properly. Some sensors only work in limited environments, some might be prone to drifting over time, and other might have too much noise in their readings. To overcome these problems, sensor readings have to be fused in different ways to obtain an accurate state of the system.

#### **Orientation Fusion**

The orientation of the drone is derived the sensor data is achieved with a 6-axis IMU(Inertial measurement unit) and a magnetometer. The Madgwick filter from xioTechnologies fusion library was used to fuse the sensor data together. The madgwick filter uses the accelerometer's xyx values to estimates the direction of gravity, and combines it with a smoother gyroscope readings to obtain orientation values. However, since direction of gravity is the same regardless of z-axis orientation, using the IMU alone cannot give a accurate z-axis reading. A magnetometer which senses the direction of Earth's magnetic field has to be used to as the absolute reference to the heading. A more mathematical explantion of the Madgwick filter can be found here: https://ahrs.readthedocs.io/en/latest/filters/madgwick.html

To obtain z-position(altitude), barometer, ToF(Time of Flight) sensor and accelerometer values from IMU were used. Barometer measures the atmospheric pressure at the current position. Since atmospheric pressure decreases with height according to the following formula:

$$
P = P_0 \cdot \left(1 - \frac{L \cdot h}{T_0}\right)^{\frac{g \cdot M}{R \cdot L}}
$$
$$
\frac{P}{P_0} = \left(1 - \frac{L \cdot h}{T_0}\right)^{\frac{g \cdot M}{R \cdot L}}
$$
$$
\left(\frac{P}{P_0}\right)^{\frac{R \cdot L}{g \cdot M}} = 1 - \frac{L \cdot h}{T_0}
$$
$$
\frac{L \cdot h}{T_0} = 1 - \left(\frac{P}{P_0}\right)^{\frac{R \cdot L}{g \cdot M}}
$$
$$
h(P) = \frac{T_0}{L} \cdot \left(1 - \left(\frac{P}{P_0}\right)^{\frac{R \cdot L}{g \cdot M}}\right)
$$

Standard Temperature ($T_0$) = $288.15 \text{ K}$
Lapse Rate ($L$) = $0.0065 \text{ K/m}$
Gravity ($g$) = $9.80665 \text{ m/s}^2$
Molar Mass of Air ($M$) = $0.0289644 \text{ kg/mol}$
Gas Constant ($R$) = $8.31432 \text{ J/(mol}\cdot\text{K)}$

Plugging these number yields: 

$$
h(P) = 44330.0 \cdot \left(1.0 - \left(\frac{P}{100.0 \cdot P_0}\right)^{\frac{1}{5.255}}\right)
$$

by which altitude can be calculated.

The ToF sensor has a limited range of up to 2m above a surface but provides much more accurate altitude readings. It uses the time it takes for light to travel to the ground surface and back to calculate the altitude. Since the ToF sensor is attatched physically to the drone, it tilts with the drone creating larger altitude readings than reality. This can be compensated for by scaling the reading by cosine of x and y orientations. 
### **Altitude Fusion**

Linear acceleration about the absolute Z-axis, altitude derived from the barometer, and the altitude readings from the compensated ToF sensor are fused using a Kalman filter. 

- **Under 2 meters (ToF in range)**: The ToF sensor acts as the absolute authority due to its millimeter-level precision. During this phase, the Kalman filter trusts the ToF heavily and simultaneously uses the ToF readings to continuously recalibrate the Barometer's ground offset.
- **Over 2 meters (ToF out of range)**: Once the drone exceeds the 2m threshold, the ToF reading becomes unreliable. The Kalman filter hands off primary altitude estimation to the barometer. Because the barometer was recalibrated just before leaving the 2m zone, the transition is seamless without sudden jumps in estimated altitude.
### **Velocity Fusion**

X and y velocities are sensed with an optical flow sensor (PMW3901) and integrated into position values. The optical flow sensor tracks patterns on ground surfaces to output angular velocity. 

Since the optical flow sensor is physically mounted to the drone body, it senses a false change in surface patterns simply when the drone tilts. Thus, the angular velocity derived from the gyroscope orientation readings must be subtracted from the optical flow readings. Another effect is parallax: closer objects seem to move faster than objects further away. The raw readings are scaled based on the current estimated altitude to obtain the true velocity. This is then fused with accelerometer values using Kalman filters for each axis.

### **Low-pass Filter**

A discrete low pass filter of form:

$$y_{n} = \alpha \cdot y_{n-1} + (1 - \alpha) \cdot x_{n}$$

was used in appropriate places to filter out noise.

### **Sensor Calibration**

Sensors need to be calibrated before use, to account for any misalignments or offsets. Magnetometer was calibrated for both soft iron and hard iron errors by using the MotionCal application to derive a 3 by 3 calibration matrix. And accelerometers are pre-calibrated to account for the PCB mounting offset and the sensor's inherent misalignments. Gyroscopes are calibrated at the beginning of every starting sequence when the drone gets power. 

# Communication

The drone communicates with the receiver using LoRa RF modules. Specifically, two **Ebyte E220-900T22D** modules are used—one onboard the drone and one at the ground station—to transmit and receive data, telemetry, and flight commands over long distances.

![[communication-diagram.png]]

###  **LoRa Configuration**

To comply with regional frequency regulations (e.g., Korea allows 920.9 ~ 923.3 MHz) and optimize for range, the Ebyte modules are configured using the following parameters:

| Setting | Value | Description |
| ---|---| ---|
| Center Frequency | 922 MHz | Legal operating band |
| Air Data Rate | 19.2 kHz  | Balances throughput and transmission distance |
| Baudrate | 115200 | UART speed between the module and MCU |
| Parity Bit | 8N1 | 8-bit data, no parity, 1 stop bit |
| Sub-packet Length  | 200 bit | Buffer size for packet splitting |
| Transmission Power | 10 dBm | Output strength |
| LBT (Listen Before Talk) | Enabled | Required by regional regulations to prevent collision |

To enter configuration mode, the M0 and M1 pins on the Ebyte module must be pulled high. The configuration commands follow the format: `command + address + length + parameters`.

Important registers to configure are:
- **REG0**: UART baud rate, Air data rate, Serial parity bit.
- **REG1**: Sub-packet length, Transmission power.
- **REG2**: Channel frequency (850.125 + REG2 MHz).
### **Asymmetric Communication Protocol**

<div align="center">
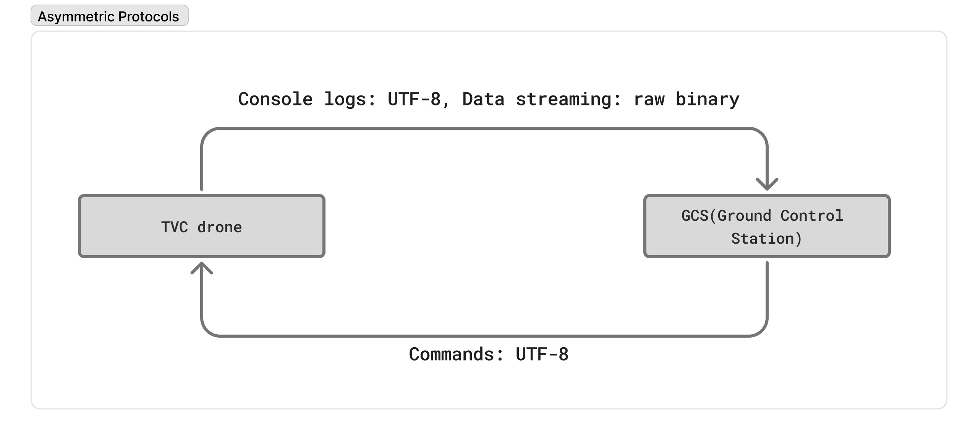
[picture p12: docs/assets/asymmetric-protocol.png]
	
</div>

A custom communication protocol, loosely modeled off of standard packet-based networking, was implemented to make the connection robust and minimize overhead. 

The communication architecture is asymmetric:
1.  Drone to GCS (Downlink): Telemetry data sent from the drone to the GCS requires high throughput and reliability. It follows a custom binary protocol, transmitting tightly packed sensor readings and status flags in raw binary to minimize packet size.
2.  GCS to Drone (Uplink): Commands sent from the GCS to the drone (e.g., arm, disarm, calibrate) are less frequent and simply use standard UTF-8 string formats.
#### **Packet Structure**

<div align="center">
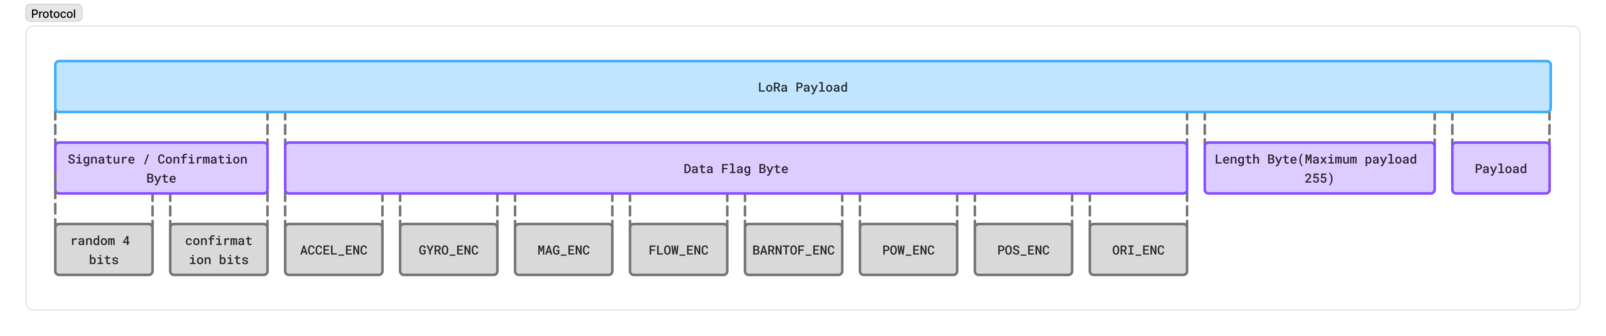
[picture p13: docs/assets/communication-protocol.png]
	
</div>

The downlink telemetry protocol is designed with a minimal 3-byte header to reduce communication overhead, ensuring the 19.2 kHz air data rate is fully utilized for actual sensor data rather than structural padding.

# FreeRTOS

The drone firmware utilizes FreeRTOS to manage multiple concurrent tasks, ensuring that hard real-time requirements (like attitude control) are never blocked by slower, less critical operations (like saving logs or receiving radio packets).

The system is split into the following primary tasks, arranged by priority:
1.  `controlTask` (Realtime Priority): The absolute core of the drone. It handles all sensor polling (via DMA to prevent CPU blocking), runs the Kalman filters, executes the LQR matrices, and commands the PWM outputs.
    - Execution Rate: The base task is triggered at 100Hz to compute the Attitude inner loops.
    - Velocity Decimation: The middle Velocity PID loop utilizes a `decimation_factor = 5`, meaning it only executes at 20Hz (once every 5 attitude cycles).
    - Position Decimation: The outer Position P loop utilizes a `decimation_factor = 10`, executing at 10Hz (once every 10 attitude cycles). This strict decimation enforces bandwidth separation across the cascaded loops.
2.  `commandTask` (High Priority): Processes incoming LoRa packets from the Ground Station. It updates the global reference targets (Roll, Pitch, Yaw, Z-Altitude) safely via FreeRTOS Mutexes.
3.  `loggerTask` (Above Normal Priority): Packs the state data into the Variable-Field Bitmask format and writes it to the SPI Flash.
4. `telemetryTask` (Normal Priority): Formats basic telemetry packets (battery voltage, altitude, drone state) and queues them for LoRa transmission back to the ground station.
5.  `transferTask` (Realtime Priority - Ground Only): This task remains entirely dormant during flight. It is only activated when the drone receives a "KILL" command. Once active, it monopolizes the CPU to rapidly read the raw SPI Flash memory and write it to the SD Card as a formatted CSV file.

### **Flight State**

The firmware relies on a strict state machine to ensure safety and prevent control windup on the ground:
1. **INIT**: System runs `sys_check()` to test buzzer, servos, motors, and sensors. 
2. **DISARMED**: Drone is idle. Sensors are running, but control loops are bypassed and motors are locked to 0. Integrals are held at zero.
3. **ARMED**: Motors spin up to an idle speed. Control loops engage to hold the current position.
4. **LAUNCH**: The Z-reference target is smoothly ramped up, commanding the drone to ascend.
5. **LAND**: The Z-reference target is slowly ramped down. Once touchdown is detected, the drone automatically disarms.

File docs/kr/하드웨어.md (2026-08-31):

# 목차
1. [설계](#설계)
	- [하드웨어 사양](#하드웨어-사양)
	- [동축 설계](#동축-설계)
	- [짐벌 설계](#짐벌-설계)
	- [바디 설계](#바디-설계)
	- [센서 배치 및 구성](#센서-배치-및-구성)
2. [PCB](#pcb)
	- [부품 개요](#부품-개요)
	- [시스템 초기화 및 점검](#시스템-초기화-및-점검)
	- [마이크로컨트롤러 및 센서](#마이크로컨트롤러-및-센서)
	- [데이터 로깅 아키텍처](#데이터-로깅-아키텍처)
	- [전원 시스템](#전원-시스템)
	- [커스텀 센서 모듈](#커스텀-센서-모듈)
	- [전원 공급 시스템](#전원-공급-시스템)
	- [듀얼 전원 USB 스위칭](#듀얼-전원-usb-스위칭)

# 설계

이 섹션에서는 드론의 하드웨어 설계와 그렇게 설계된 이유를 설명합니다. 제작 과정에서 핵심 하드웨어 구성 요소와 주요 설계 선택이 이루어졌으며, 각각은 아래 하위 섹션에서 설명됩니다.

1. 하드웨어 사양
2. 동축(Coaxial) 설계
3. 짐벌 설계
4. 바디 설계

### **하드웨어 사양**
드론은 비행을 구현하기 위해 다음과 같은 핵심 하드웨어 구성 요소를 사용합니다:
- **모터**: DZP30 카운터 로테이팅 모터(KV: 1500, 추력: 개당 약 280g, 전류: 11.1V에서 0.5A).
- **ESC**: XP-12A(12A 정격, BEC 내장).
- **프로펠러**: 7035(직경 7인치, 피치 3.5인치, 3엽, 5mm 내경).
- **배터리**: JST 커넥터를 사용하는 3S 1500mAh 45C 리포(LiPo).

### **동축(Coaxial) 설계**
z축 토크를 거의 발생시키지 않는 일반적인 로켓 엔진과 달리, 프로펠러가 달린 스피닝 모터를 사용하면 z축 토크가 발생합니다. z축 회전 동역학은 두 가지 요인에 의해 결정됩니다. 모터가 회전하는 동안 항상 존재하는 주요 동역학은 모터의 회전 방향과 반대 방향으로 작용하는 토크입니다. 이 동역학은 완전한 진공 상태에서 모터가 가속되지 않을 때는 존재하지 않을 것입니다. 가속이 없으면 각운동량의 변화가 없으므로 사실상 토크는 0입니다. 그러나 현실 세계에서는 모터에 부착된 프로펠러가 공기 분자를 가속시켜 추력을 만들어내는데, 뉴턴의 제3법칙에 따라 이는 반대 방향의 힘을 유발합니다. 이는 모터를 감속시키는 효과를 낳습니다. 일정한 각속도를 유지하기 위해서는 모터가 계속 가속해야 하며, 따라서 모터가 각속도를 유지하고 있을 때조차도 기체에는 그와 동일하고 반대되는 토크가 발생합니다. 두 번째로, 또 다른 관련 동역학은 각운동량 보존입니다. 이는 모터가 각속도를 증가시키거나 감소시키며 가속할 때 나타납니다.

드론이 안정성을 확보하려면 z축을 제어할 수 있어야 합니다. 이것이 동축 설계를 선택한 이유입니다. 서로 반대 방향으로 회전하는 두 모터를 사용하면 토크가 서로 상쇄됩니다. 두 모터가 동일한 각속도로 회전하고 동일한 양의 추력을 생성하는(각각 전체 추력의 절반을 생성하는) 이상적인 시나리오에서는, 생성되는 토크가 동일한 크기를 가지며 서로 반대 방향을 향해 순 토크가 0이 되어야 합니다. 그러나 현실은 이상적인 경우와는 거리가 멉니다. 두 프로펠러가 위아래로 겹쳐 있기 때문에 위쪽 프로펠러에서 발생하는 기류가 이상적인 시나리오로부터의 불규칙성을 만들어냅니다. 따라서 각 카운터 로테이팅 모터의 각속도를 개별적으로 제어할 수 있어야 합니다. 한 모터를 가속하고 다른 모터를 적절히 감속시킴으로써, 이 시스템은 동일한 양의 추력을 생성하면서도 원하는 방향의 토크를 만들어낼 수 있습니다.

### **짐벌 설계**
짐벌은 저렴하고 널리 구할 수 있는 MG90S 서보 두 개를 사용합니다. 메탈 기어 서보는 소프트 기어 서보에 비해 백래시가 훨씬 적기 때문에 특별히 선택되었습니다. 이 특정 모델은 저렴한 가격 때문에 선택되었습니다. 두 축 모두 3D 프린팅된 기어를 사용하여 각 모터가 생성해야 하는 토크의 양을 줄이고, 짐벌 제어가 더 정밀해지도록 했습니다. 그러나 기어를 사용함으로써 자체적인 백래시 문제가 발생했으며, 이는 서로 다른 기어 지름을 반복적으로 테스트하여 줄여야 했습니다.

설계상 한쪽 기어는 일반적인 3:1 감속비를 가지며, 다른 쪽은 4:1 감속비를 가집니다. 이는 서보가 장착된 기하학적 구조 때문입니다. 서보-x는 일반 기어처럼 작동하며 고정된 회전축을 가지고 3:1의 기어비를 가지는데, 이는 아래 단면 분석에서 확인할 수 있습니다.

<div align="center">
	
</div>

그러나 서보-y에 부착된 기어는 회전하면서 TVC 축을 중심으로 공전합니다. 이러한 축의 회전으로 인해 TVC가 360도 회전할 때 서보가 추가로 한 바퀴를 더 회전해야 하며, 이 때문에 기어비가 4:1이 됩니다. 이 효과는 소프트웨어에서 TVC 각도를 관리할 때 반드시 고려해야 합니다.

<div align="center">
	
</div>

### **바디 설계**
바디 프레임은 드론을 가볍고 강성 있게 만들기 위해 적절한 길이로 절단된 3mm 솔리드 탄소 섬유 막대로 구성되었습니다. 이 막대들은 맞춤 설계된 3D 프린팅 부품으로 서로 연결됩니다. 막대는 3D 프린팅 부품에 뚫린 구멍의 지름을 나사 지름보다 약간 작게 만들어 나사로 고정됩니다. 나사가 들어가는 위치의 막대에는 작은 홈이 만들어져 있어 막대를 제자리에 고정합니다.

바디는 길게 제작되었으며, (배터리, 모터, 무선 안테나를 포함한) 대부분의 질량이 무게중심에서 멀리 떨어진 위치에 의도적으로 배치되었습니다! 관성 모멘트는 다음과 같이 표현되므로

$$I = \sum_{i=1}^{n} m_i r_i^2$$

여기서 $r_i$는 작은 질량 $m_i$가 무게중심으로부터 떨어진 거리인데, 질량을 가진 부품들을 분산 배치하면 물체의 관성 모멘트가 증가합니다. 관성 모멘트가 증가하면 드론이 전복되는 속도가 느려지는데, 관성 모멘트는 정의상 각속도 변화에 대한 저항이기 때문입니다.

이 설계 선택에 대한 다른 이유는 비례 제어기를 사용하는 동일한 2차원 시스템의 간단한 예시를 통해 명확히 확인할 수 있습니다. 오차(원하는 각도 0으로부터의 오차인 $\theta$)에 비례하여 TVC 짐벌을 기울이는 방식으로 반응하는 시스템을 상상해 봅시다.

작은 TVC 편향각 $\phi$에 대해,

$$ \tau = -F_t \cdot d \cdot \sin(\phi) \approx F_t \cdot d \cdot \phi$$
$$ I_{cg} \ddot \theta = -F_t \cdot d \cdot \phi$$

우리가 모델링하는 것은 비례 제어기이므로,

$$\phi = K_p \theta$$
$$ I_{cg} \ddot \theta = -F_t \cdot d \cdot K_p \theta$$
$$  \ddot \theta + \frac {F_t \cdot d \cdot K_p}{I_{cg}} \theta = 0$$

이는 다음과 같이 표현되는 비감쇠 조화 진동자(undamped harmonic oscillator)의 방정식과 유사합니다.
$\ddot x + \omega_n^2 x = 0$ (여기서 $\omega$는 시스템의 고유 진동수입니다).

따라서 이 시스템의 폐루프 고유 진동수는 다음과 같이 표현할 수 있습니다.

$$\omega_n = \sqrt{\frac {F_t \cdot d \cdot K_p}{I_{cg}}}$$

이 모델을 통해 $I_{cg}$가 감소함에 따라 폐루프 고유 진동수가 증가한다는 것을 알 수 있습니다. 작은 $I_{cg}$는 목표 각도 주변에서 빠르고 고주파의 진동을 유발합니다. 이는 실제 TVC 드론에서 매우 문제가 되는데, 50Hz 서보 갱신 주기와 0이 아닌 서보 이동 시간 같은 물리적인 하드웨어 제약이 이상적인 모델에서는 생략되기 때문입니다. 고주파와 서보 지연이 결합되면 치명적인 위상 지연이 유발되어 불안정으로 이어집니다. $I_{cg}$를 증가시킴으로써, 우리는 가벼운 기체의 혼란스러운 고주파 회전 동역학으로부터 제어 권한을 조정 가능한 소프트웨어 파라미터인 $K_{p}$로 효과적으로 이동시킬 수 있습니다. 커진 $I_{cg}$는 고유 진동수 상한을 억제하여, 서보의 물리적 대역폭 한계를 넘지 않으면서도 바람에 의한 외란을 강하게 억제하기 위해 $K_{p}$를 공격적으로 높일 수 있게 해줍니다.

### **센서 배치 및 구성**
정확한 상태 추정을 위해서는 적절한 센서 배치와 구성이 매우 중요하며, 특히 지면과 직접 상호작용하는 센서의 경우 더욱 그렇습니다.

- **IMU (ICM-42688-P)**: `main.c`에서 $\pm8$G 가속도 및 $\pm500$도/초로 설정되었으며, 필터링 전 위상 지연을 최소화하기 위해 1760Hz로 샘플링됩니다.
- **기압계 (BMP388)**: 노이즈 감소와 응답성 사이의 균형을 맞추기 위해 50Hz로, 압력에 대해 8배 오버샘플링으로 설정되었습니다.
- **ToF(Time of Flight) 센서 (VL53L1X)**: 고도를 측정하기 위해 드론의 다리 중 하나에 아래를 향하도록 배치되었습니다. 이 센서는 이론적으로 최대 4미터까지 측정 가능하며, 이는 저고도 착륙 및 호버링 단계에 완벽하게 부합합니다.
- **광류 센서 (PMW3901)**: 공간 제약과 시야선(line-of-sight) 요구사항 때문에 ToF 센서가 장착된 다리의 반대쪽에 위치한 외부 다리에 장착되어 있습니다. 다리 마운트가 각도를 이루고 있기 때문에, 센서 고유의 X, Y축은 비행 컨트롤러의 기본 좌표계에 대해 45도 각도로 놓이게 됩니다. 이를 보정하기 위해 펌웨어는 원시 PMW3901 판독값을 속도 추정기에 융합하기 전에 수학적으로 45도 회전시킵니다.

# PCB

이 섹션에서는 비행 컨트롤러 PCB의 아키텍처 및 하드웨어 설계 선택을 설명하며, 부품 선정과 전원 공급에 중점을 둡니다.

이 PCB는 오픈소스 전자 설계 자동화 도구인 KiCAD를 사용하여 설계되었습니다. 부품 선정은 TVC 드론의 성능, 안정성, 향후 확장성을 좌우하기 때문에 매우 중요했습니다.

### **부품 개요**

| 구분 | 모델 | 인터페이스 | 용도 |
| --- | --- | --- | --- |
| MCU | STM32F722RET | SWD | 메인 비행 컨트롤러 프로세서 |
| IMU | ICM-42688-P | SPI | 6축 자이로스코프 및 가속도계 |
| 지자기 센서 | BMM150 | I2C | Z축 회전 및 절대 방위 |
| 기압계 | BMP388 | SPI | 고도 및 온도 감지 |
| GPS | U-blox NEO-7 | UART/Custom | 위성항법시스템 |
| 전력 센서 | INA226 | I2C | 배터리 전압 및 전류 모니터링  |
| 플래시 메모리 | W25Q128JVSIQ | SPI | 16MB 온보드 비행 데이터 로깅 |
| SD 카드 | TF-01A | SDMMC | 탈착식 비행 후 데이터 저장 |
| USB OTG | USB4105-GF-A-120 | USB-C | 디버깅 및 데이터 추출 |
| 전원 멀티플렉서 | TPS2121 | - | 지능형 배터리/USB 전원 전환 |
| 부저 | MLT-8540 | GPIO | 시청각 피드백 |

### **시스템 초기화 및 점검**

부팅 시 비행 컨트롤러는 `sys_init()` 함수를 실행하여 시스템을 초기화합니다. 이 함수는 드론의 모든 구성 요소를 초기화하고 GCS(지상 관제국)와의 연결을 시도합니다.

이후 GCS에서 "CHECK" 명령을 전송하면 `sys_check()` 함수를 실행할 수 있습니다. 이는 발사 전에 모든 센서와 구성 요소가 정상적으로 작동하는지 확인합니다. 이 함수는 다음을 포함합니다.

1. **시청각 피드백**: 부저와 LED를 테스트합니다.
2. **액추에이터 스윕**: X, Y 서보와 메인 모터를 제한된 범위로 구동시켜 ESC 및 서보 응답을 확인합니다.
3. **센서 폴링**: IMU(ICM-42688-P), 지자기 센서(BMM150), 기압계(BMP388), 전력 센서(INA226)가 SPI/I2C DMA 요청에 정상적으로 응답하는지 확인합니다.
4. **메모리 검증**: W25Q128 플래시 메모리의 테스트 섹터를 지우고 쓰기를 수행하며, SD 카드에 모의 CSV 파일을 작성하여 비행 중 데이터 로깅이 실패하지 않도록 합니다.

### **마이크로컨트롤러 및 센서**

**MCU(마이크로컨트롤러 유닛)**는 자세 제어 루프 실행, 센서 데이터 읽기, 서보 및 모터 명령을 담당합니다. STM32F722RET는 작은 크기, 높은 클럭 속도, 풍부한 하드웨어 주변장치(SPI, I2C, SDMMC) 덕분에 선택되었습니다.

**IMU(관성 측정 장치)**는 자세 안정화에 필요한 기본적인 자이로스코프 및 가속도계 판독값을 제공합니다. IMU는 X축과 Y축 회전(피치와 롤)은 정확하게 추적할 수 있지만, 드리프트 없이 절대적인 Z축 방향(요)을 결정할 수는 없습니다. 따라서 지구 자기장을 감지하여 드리프트 없는 요(yaw) 측정값을 제공하는 **지자기 센서(BMM150)**가 포함되어 있습니다.

**기압계(BMP388)** 또한 미세한 대기압 변화를 감지하여 비행 컨트롤러가 드론의 고도를 추정할 수 있도록 포함되어 있습니다.

### **데이터 로깅 아키텍처**
디버깅 및 성능 튜닝을 위해서는 견고한 로깅 시스템이 필수적입니다. 이 PCB는 고속 데이터를 처리하기 위해 2단계 로깅 방식을 사용합니다.

1.  **비행 중(고속)**: 비행 중에는 센서 데이터와 제어 변수가 SPI를 통해 온보드 **W25Q128JVSIQ 16MB 플래시 메모리**에 기록됩니다. 비행 중 물리적인 SD 카드에 직접 쓰는 것은 피하는데, 기계적 진동으로 인해 순간적인 연결 끊김이 발생하여 치명적인 지연 스파이크나 파일 손상을 초래할 수 있기 때문입니다. 플래시 메모리는 **가변 필드 비트마스크 직렬화(Variable-Field Bitmask Serialization)** 형식을 사용하여 256바이트 페이지에 필요한 필드만 촘촘하게 압축함으로써 16MB 용량을 최대한 활용합니다.
2.  **비행 후(데이터 추출)**: 비행 컨트롤러가 "KILL" 명령(기체 시동 해제)을 수신한 후, 로깅된 이진 데이터는 플래시 메모리에서 **MicroSD 카드**로 자동으로 옮겨지며, 이때 읽을 수 있는 CSV 형식(`flight.csv`)으로 변환됩니다. 이 방식은 데이터 무결성을 보장하는 동시에 지상 관제국에서 분석하기 쉬운 파일을 제공합니다. 이 접근 방식은 BPS.Space의 비행 컨트롤러 설계에서 많은 영감을 받았습니다.
### **전원 시스템**
전원 분배는 안정적인 비행을 위해 필수적이며, 특히 고전류 서보 및 모터가 민감한 I2C 센서와 동일한 전원을 공유할 때 더욱 그렇습니다.

- INA226 전력 센서는 초고속 140µs 전압 변환 시간을 갖도록 명시적으로 구성되어 있습니다. 이는 배터리 전압 원격 측정이 엄격한 100Hz 실시간 자세 제어 루프의 병목이 되지 않도록 보장합니다.
- 3.3V 강압 변환기가 로직 부품에 전원을 공급하기 위해 3S 리포 배터리 전압을 효율적으로 낮추는 데 사용됩니다.
- 메인 배터리는 ESC와 서보를 직접 구동하여, 대규모 전류 스파이크가 로직 레일에 영향을 미치지 않도록 합니다.

### **커스텀 센서 모듈**
PMW3901(광류)과 VL53L1X(ToF) 센서는 메인 비행 컨트롤러 PCB에 내장된 센서가 아니라 별도의 모듈로 사용됩니다.
- 이를 통해 드론 프레임이나 프로펠러의 간섭을 최소화하는 최적의 아래쪽 배치가 가능합니다.
- 이러한 유연성 덕분에 충돌로 인해 다리 부분의 센서가 손상되더라도 비행 컨트롤러 스택 전체가 아닌 작은 모듈만 교체하면 됩니다.
- **DMA 및 세마포어 안전성**: 이 센서들은 외부 배선을 통해 통신하기 때문에 전기적 노이즈나 비행 중 연결 끊김에 취약합니다. 손상된 I2C/SPI 버스가 CPU를 멈추게 하여 드론이 추락하는 것을 방지하기 위해, 모든 센서 폴링은 하드웨어 DMA 채널로 오프로드되며, FreeRTOS 뮤텍스로 감싸져 있고 OS 수준의 타임아웃으로 제한됩니다.

### **전원 공급 시스템**

전원 경로는 다음과 같은 경로를 따릅니다: +BATT -> 모터 -> +5V -> 서보 -> +3.3V -> STM32 및 센서.

ESC의 제한적인 배터리 제거 회로(BEC, Battery Elimination Circuit)에 의존하는 일반적인 쿼드콥터와 달리, 이 TVC 드론은 비행 중 지속적으로 구동되어야 하는 2개의 온보드 서보를 위해 상당한 전류를 필요로 합니다. 이를 해결하기 위해 PCB는 나사 단자를 통해 3S 리포 배터리로부터 직접 전원을 공급받으며, 온보드에서 전압을 강하시킵니다:

*   **벅 컨버터(MP2393)**: +11.1V(3S 리포)를 안정적인 +5V로 낮춰 MG90S 서보에 전원을 공급합니다. MP2393은 상당한 전류 소모 조건에서도 높은 효율을 제공하기 때문에 선택되었습니다. 파워 굿(PG) 핀은 전원 상태 모니터링을 위해 STM32 GPIO에 연결되어 있습니다(현재는 사용하지 않음).

*   **리니어 레귤레이터(AMS1117-3.3)**: +5V 레일을 STM32 MCU와 민감한 I2C/SPI 센서에 전원을 공급하기 위한 깨끗한 +3.3V로 낮춥니다.

### **듀얼 전원 USB 스위칭**
비행 컨트롤러는 벤치 테스트 중 리포 배터리 또는 USB-C 연결 중 어느 쪽으로도 전원을 공급받을 수 있습니다. 배터리가 연결된 상태에서 USB 포트로 전압이 역류하는 위험한 상황을 방지하기 위해 **TPS2121 전원 멀티플렉서**가 사용됩니다. 이는 배터리 입력(IN1)이 3.3V 이상으로 유지되는 한 이를 자동으로 우선시하도록 구성되어 있어, 매끄러운 전원 전환과 VBUS 보호를 제공합니다. **INA226** IC 또한 배터리의 전압과 전류 소모를 모니터링하기 위해 회로에 배치되어 있으며, 배터리가 방전됨에 따라 동적인 ESC 스로틀 보정을 가능하게 합니다.

또한 USB 연결을 정전기 방전(ESD)으로부터 보호하기 위해 데이터 라인은 **USBLC6-2SC6**로 보호되며, VBUS 라인은 **ESDA7P60-1U1M**로 보호됩니다. VBUS 감지 회로는 MCU가 실제로 연결이 감지되었을 때만 USB 통신을 시도하도록 합니다.

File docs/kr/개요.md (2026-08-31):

# 목차

1. [동기](#동기)
2. [표기 규칙](#표기-규칙)
3. [시스템](#시스템)
4. [제어](#제어)
5. [튜닝](#튜닝)
6. [특징](#특징)

# 동기

이 드론은 무게중심 아래쪽에서 추력을 발생시킨다는 점에서 로켓의 동역학을 재현하도록 설계되었습니다. 그러나 이러한 구조는 본질적으로 불안정하여, 작은 초기 기울어짐만으로도 로켓이 전복될 수 있습니다. 실제 로켓은 주로 다음 두 가지 전략으로 이 문제를 해결합니다.

1. 고속 비행 시 압력중심(center of pressure)을 무게중심(center of gravity)보다 낮게 위치시키는 방법
2. 로켓의 자세를 능동적으로 제어하는 시스템을 사용하는 방법

첫 번째 방법은 로켓이 원래 진행 방향으로 공기 중을 이동할 때만 적용될 수 있기 때문에, 발사나 착륙 시에는 로켓을 안정화할 별도의 메커니즘이 반드시 필요합니다.
가장 널리 사용되는 제어 메커니즘 중 하나가 바로 TVC(추력 벡터 제어, Thrust Vector Control)입니다. 간단히 설명하면, 이는 추력의 방향을 바꾸어(vectoring) 로켓을 안정화하는 방법입니다. 이 프로젝트는 TVC 기술을 이용해 제어 비행을 구현하는 것을 목표로 하며, TVC 제어 시스템의 견고함을 시험하기 위한 VTVL(수직 이착륙, Vertical Takeoff Vertical Landing) 드론을 제작합니다.
3D CAD 모델, 비행 컨트롤러 PCB, 통신 프로토콜, 소프트웨어를 포함한 이 프로젝트의 대부분의 자원은 제작자가 드론 시스템을 완전히 통제할 수 있도록 처음부터 직접 제작되었습니다.

# 표기 규칙

드론의 좌표계와 그에 대응하는 각도는 아래 다이어그램에 나타나 있습니다. 문서 전반에 걸쳐 롤(roll, x축 회전), 피치(pitch, y축 회전), 요(yaw, z축 회전)라는 용어를 사용합니다.

# 시스템

시스템은 크게 두 부분으로 나뉩니다.

1. 드론: FreeRTOS 타이머 트리거 기반으로 동작하는 STM32F722RET 마이크로컨트롤러로 구동됩니다. 모든 시간 critical한 센서 퓨전, 안정화, 데이터 로깅, 액추에이터 명령을 담당합니다.
2. 지상 관제국(GCS, Ground Control Station): 물리 조이스틱과 호스트 PC에 연결되는 ESP32 마이크로컨트롤러로 구동됩니다. 원격 측정 데이터 디코딩, 비행 모드 전환, 장거리 LoRa RF를 통한 조작자 명령 전달을 담당합니다.

# 제어

추력 벡터 방식 기체가 본질적으로 지닌 불안정성에도 불구하고 안정화와 제어 비행을 달성하기 위해, 비행 컨트롤러는 3단계 캐스케이드(cascading) 제어 루프를 사용합니다.

1. 위치(외곽 루프 - P 제어기): 원하는 3차원 좌표를 확인하고, 그곳에 도달하는 데 필요한 목표 속도를 계산합니다.
2. 속도(중간 루프 - PID 제어기): 목표 속도를 확인하고, 드론을 올바른 방향으로 가속시키는 데 필요한 기체 기울기(목표 롤/피치 각도)를 계산합니다.
3. 자세(내부 루프 - LQR 제어기): 목표 자세각을 받아, 오버슈트 없이 드론을 물리적으로 원하는 방향으로 정렬하는 데 필요한 최적의 신속한 액추에이터 명령(서보 각도 및 모터 추력)을 계산합니다.

# 튜닝

LQR 제어기는 수학적으로 완벽한 보정값을 계산할 수 있지만, 실제 서보는 유한한 이동 시간과 50Hz PWM 갱신 주기의 제약을 받습니다. 소프트웨어가 서보가 물리적으로 추종할 수 없는 고주파 진동을 요구하면 위상 지연(phase lag)이 발생하여 치명적인 불안정을 초래합니다. 따라서 제어 철학은 소프트웨어를 제약하는 데(최대 속도 클램핑, P 게인 제한, D항 필터링) 크게 의존하며, 이를 통해 하드웨어의 물리적 대역폭 한계를 존중합니다.

# 특징

프로젝트 목표에 따라 설계 시 다음과 같은 요구사항을 충족했습니다.

* LoRa를 통한 무선 통신
* 수직 이착륙(VTVL) 가능
* 온보드 플래시 메모리 및 Micro SD를 통한 데이터 로깅
* 2개의 카운터 로테이팅 모터 및 4개의 짐벌 서보 제어
* STM32 기반 비행 컨트롤러
* 시청각 피드백(부저 및 LED)
* VCC 및 GND, 추가 센서용 외부 핀
* 배터리 전압 및 전류 모니터링
* 디버깅 및 이중 전원 전환을 위한 USB-C 인터페이스
* 센서 구성: 지자기 센서, 가속도계, 자이로스코프, 기압계(온도/압력)

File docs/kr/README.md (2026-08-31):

# 목차

이 문서는 프로젝트 문서의 색인입니다. 아래 링크를 클릭하여 원하는 섹션으로 이동하세요.

1. [개요](개요.md)
2. [하드웨어](하드웨어.md)
3. [소프트웨어](소프트웨어.md)

> 주의사항
>
> 이 프로젝트는 개인이 AI의 도움을 받아 개발 및 문서화했습니다. 시간과 인력 부족으로 인해 프로젝트의 일부 코드와 글은 AI가 생성하고 사람이 검토한 내용을 포함할 수 있습니다. 이 프로젝트는 완벽하지 않으며, 단계별 제작 가이드가 아닌 참고 자료로만 사용하시길 권장합니다.

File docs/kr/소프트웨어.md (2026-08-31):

# 목차
1. [제어](#제어)
	- [LQR](#lqr)
	- [비용 함수와 이산 대수 리카티 방정식(DARE)](#비용-함수와-이산-대수-리카티-방정식dare)
	- [최적 게인과 제어 법칙](#최적-게인과-제어-법칙)
	- [PID](#pid)
	- [적분 와인드업 방지 메커니즘](#적분-와인드업-방지-메커니즘)
	- [LQR 서보 매핑](#lqr-서보-매핑)
2. [센서 퓨전](#센서-퓨전)
	- [자세 퓨전](#자세-퓨전)
	- [고도 퓨전](#고도-퓨전)
	- [속도 퓨전](#속도-퓨전)
	- [저역 통과 필터](#저역-통과-필터)
	- [센서 보정](#센서-보정)
3. [통신](#통신)
	- [LoRa 구성](#lora-구성)
	- [비대칭 통신 프로토콜](#비대칭-통신-프로토콜)
	- [패킷 구조](#패킷-구조)
	- [FreeRTOS](#freertos)
	- [비행 상태](#비행-상태)

# 제어

TVC 시스템을 구현하는 방법에는 크게 네 가지가 있습니다: 움직이는 핀(movable fins), 짐벌 추력(gimbaled thrust), 버니어 로켓(vernier rocket), 추력 베인(thrust vanes).

<div align="center">
	
</div>

그러나 SpaceX의 팰컨 9와 스타십, 로켓랩의 일렉트론, NASA의 SLS, KARI의 누리(KSLV-II), JAXA의 H3, CASC의 창정, ESA의 아리안 등 대부분의 현대 로켓들은 비행 중 조종성을 확보하기 위해 짐벌 추력 방식을 사용합니다.

전반적으로 드론에서 제어 가능한 값은 서보-x, 서보-y, 모터1, 모터2에 대한 PWM 신호입니다. 이를 통해 드론은 x, y, z축 전체에 걸쳐 자세와 위치를 제어할 수 있습니다.
### **LQR**

드론의 자세와 고도를 제어하는 데 사용되는 제어 방식 중 하나는 **LQR(선형 이차 조절기, Linear Quadratic Regulator)**입니다. 이는 시스템의 현재 상태를 반영하는 상태 벡터와, 시스템의 물성치를 이용해 사전에 계산된 행렬을 사용하여 오차를 최소화하는 방향으로 액추에이터를 구동합니다. 게인 행렬이 사전에 최적으로 계산되기 때문에, 번거로운 수동 튜닝 과정을 생략할 수 있으며, 오차 종류와 액추에이터 사용 페널티 간의 균형을 맞추기 위한 벤치 테스트만 필요로 합니다.

이 제어기는 자세/고도 오차와 그 미분값, 적분값으로 구성된 12개 상태의 증강 벡터를 대상으로 동작합니다.

$$
\mathbf{x} = \begin{bmatrix} r_x & r_y & r_z & p_z & \dot{r}_x & \dot{r}_y & \dot{r}_z & \dot{p}_z & \int r_x & \int r_y & \int r_z & \int p_z \end{bmatrix}^T \in \mathbb{R}^{12}
$$

여기서 $r_x, r_y, r_z$는 롤/피치/요 자세 오차이고, $p_z$는 고도(위치-z) 오차이며, $\dot{(\cdot)}$ 항은 각각의 변화율, $\int(\cdot)$ 항은 정상상태 오차 제거를 위해 추가된 누적 적분값입니다.

이 시스템은 다음과 같은 선형 시불변(LTI) 플랜트로 모델링됩니다.

$$
\dot{\mathbf{x}} = A_c \mathbf{x} + B_c \mathbf{u}
$$

여기서 상태 행렬 $A_c$는 운동학적 관계를 나타냅니다.

$$
A_c =
\left[\begin{array}{cccccccccccc}
0&0&0&0&1&0&0&0&0&0&0&0\\
0&0&0&0&0&1&0&0&0&0&0&0\\
0&0&0&0&0&0&1&0&0&0&0&0\\
0&0&0&0&0&0&0&1&0&0&0&0\\
0&0&0&0&0&0&0&0&0&0&0&0\\
0&0&0&0&0&0&0&0&0&0&0&0\\
0&0&0&0&0&0&0&0&0&0&0&0\\
0&0&0&0&0&0&0&0&0&0&0&0\\
1&0&0&0&0&0&0&0&0&0&0&0\\
0&1&0&0&0&0&0&0&0&0&0&0\\
0&0&1&0&0&0&0&0&0&0&0&0\\
0&0&0&1&0&0&0&0&0&0&0&0
\end{array}\right]
$$

그리고 입력 행렬 $B_c$는 액추에이션 벡터 $\mathbf{u} = \begin{bmatrix} u_0 & u_1 & u_2 & u_3 \end{bmatrix}^T$(서보-x, 서보-y, 차동 추력, 메인 추력)를 물리적 제어 효율 상수 $B_{rx}$, $B_{ry}$, $B_{rz}$, $B_{pz}$로 스케일링하여 변화율 상태로 매핑합니다. $B_{rx}$와 $B_{ry}$ 값은 바이필러 진자(bifilar pendulum)를 사용해 x, y축에 대한 무게중심 관성 모멘트를 계산하여 구했으며, $B_{rz}$는 다양한 모터 rpm 차이에서의 z축 각가속도를 실험적으로 측정하여 구했습니다. 마지막으로 $B_{pz}$는 단순히 드론의 최종 질량을 이용해 계산되었습니다.

$$
B_c =
\left[\begin{array}{cccc}
0&0&0&0\\
0&0&0&0\\
0&0&0&0\\
0&0&0&0\\
-B_{rx}&0&0&0\\
0&B_{ry}&0&0\\
0&0&B_{rz}&0\\
0&0&0&B_{pz}\\
0&0&0&0\\
0&0&0&0\\
0&0&0&0\\
0&0&0&0
\end{array}\right]
$$

비행 컨트롤러는 고정된 제어 루프 주기로 동작하므로, 연속 시간 플랜트는 샘플 시간 $\Delta t$의 영차 유지(zero-order hold)를 통해 이산 시간으로 변환됩니다.

$$
\mathbf{x}_{k+1} = A_d \mathbf{x}_k + B_d \mathbf{u}_k, \qquad (A_d, B_d) = \mathrm{ZOH}(A_c, B_c, \Delta t)
$$

LQR 게인은 다음과 같은 무한 구간 이차 비용을 최소화함으로써 구해집니다.

$$
J = \sum_{k=0}^{\infty} \left( \mathbf{x}_k^T Q \, \mathbf{x}_k + \mathbf{u}_k^T R \, \mathbf{u}_k \right)
$$

여기서 $Q \in \mathbb{R}^{12\times12}$는 상태 오차(자세, 변화율, 적분항)에, $R \in \mathbb{R}^{4\times4}$는 액추에이터 사용에 페널티를 부여합니다.

$$
Q = \text{diag}\big(q_{r_x},\, q_{r_y},\, q_{r_z},\, q_{p_z},\, q_{\dot r_x},\, q_{\dot r_y},\, q_{\dot r_z},\, q_{\dot p_z},\, q_{\int r_x},\, q_{\int r_y},\, q_{\int r_z},\, q_{\int p_z}\big)
$$

$$
R = \text{diag}\big(r_{u_0},\, r_{u_1},\, r_{u_2},\, r_{u_3}\big)
$$

최적 비용-투-고(cost-to-go) 행렬 $P$는 DARE를 풀어 구합니다.

$$
P = A_d^T P A_d - A_d^T P B_d \left( R + B_d^T P B_d \right)^{-1} B_d^T P A_d + Q
$$

이는 파이썬(`lqr_compute.py`) 또는 매트랩(`lqr_compute.m`)을 사용하여 풀 수 있습니다.

최적 피드백 게인 행렬은 $P$로부터 다음과 같이 직접 계산됩니다.

$$
K = \left( R + B_d^T P B_d \right)^{-1} B_d^T P A_d
$$

그리고 각 시간 단계에서 적용되는 제어 입력은 다음과 같은 선형 피드백 법칙입니다.

$$
\mathbf{u}_k = -K \, \mathbf{x}_k
$$

$K$는 전체 12개 상태의 증강 시스템에 대해 한 번만 계산되기 때문에, 서보, 차동 추력, 추력 벡터링 채널에 대한 게인들이 이미 서로 균형을 이루고 있습니다. 이를 통해 수동 PID 방식 튜닝의 필요성이 사라지며, 오차 억제와 액추에이터 사용 비용 간의 상대적 가중치를 미세 조정하기 위한 벤치 테스트만 남게 됩니다.
### **PID**
대부분의 드론은 비행 중 안정성을 유지하기 위해 PID(비례-적분-미분, Proportional Integral Derivative) 제어 방식을 사용합니다. 이 방식에서는 오차에 대한 제어 출력이 비례, 적분, 미분 게인 각각에 대해 튜닝된 계수로 구동됩니다. 비례항은 오차를 줄이는 방향으로 시스템을 유도하고, 적분항은 시스템의 부정확성을 보정하며, 미분항은 그렇지 않으면 진동하게 될 시스템에 대한 감쇠 역할을 합니다. 이에 대한 좋은 설명 영상이 있습니다: https://youtu.be/4Y7zG48uHRo?si=Jpp3Fp_0xEZwwcJJ

$$u(t) = K_p e(t) + K_i \int_{0}^{t} e(\tau) \, d\tau + K_d \frac{d e(t)}{dt}$$

적분과 미분은 이산 시간에서 계산상으로 계산되어야 하므로 이 함수는 다음과 같이 됩니다.

$$u(t_n) = K_p e(t_n) + K_i \sum_{k=0}^{n} e(t_k) \Delta t + K_d \frac{e(t_n) - e(t_{n-1})}{\Delta t}$$

XY(수평) 위치는 **캐스케이드 구조**를 사용하여 제어되었습니다. 이 캐스케이드 구조에서는, 목표 XY 자세는 XY 속도를 조절하는 PID 제어기에 의해 결정됩니다. 그리고 목표 XY 속도는 다시 XY 위치 오차를 조절하는 P 제어기에 의해 결정됩니다.

1. 위치 오차 → 목표 속도(P 제어기): 가장 바깥쪽 루프는 원하는 목표 좌표와 현재 3차원 위치 간의 차이를 계산합니다. 단순한 비례(P) 제어기가 이 거리 오차를 목표 속도로 변환합니다. 이를 통해 드론이 목표 지점으로 순간이동을 시도하는 대신, 통제된 속도로 이동하게 됩니다.
   - 튜닝($K_p$ = 0.5): 펌웨어는 X, Y축 모두에 대해 매우 보수적인 게인인 0.5를 사용합니다.
   - 클램핑: 이 단계의 출력은 큰 위치 변화 시 발생할 수 있는 불안정하고 고속의 급격한 움직임을 방지하기 위해 $\pm0.5$ m/s로 엄격하게 제한됩니다.

1. 속도 오차 → 목표 자세(PID 제어기): 중간 루프는 (광류 센서와 IMU 융합으로부터 얻은) 현재 추정 속도를 위치 루프에서 제공된 목표 속도와 비교합니다. 완전한 비례-적분-미분(PID) 제어기를 사용하여 목표 롤/피치 각도를 출력합니다. 앞으로 가속하려면 드론이 앞으로 기울어져야 합니다.
   - 튜닝($K_p$ = 0.140, $K_i$ = 0.040, $K_d$ = 0.008): 여기서의 게인들이 외곽 루프에 비해 훨씬 작다는 점에 주목하세요.
   - 클램핑: 목표 자세 출력은 $\pm0.2$ 라디안(약 $11.4^\circ$)으로 엄격하게 제한됩니다. 이 엄격한 제한은 드론이 양력을 저해하거나 회복 불가능한 전복을 유발할 수 있는 극단적인 기울기를 명령하지 않도록 방지합니다.

<div align="center">
	
</div>

위치 제어는 드론의 드리프트를 방지하고자 할 때 필수적입니다. 드론이 무게중심 아래에서 추력을 생성하기 때문에, 이는 역진자(inverted pendulum)와 동역학적으로 유사합니다. 이는 본질적으로 불안정하며 전복되려는 경향이 있습니다. 더욱이 짐벌을 한 방향으로 기울이면 회전 토크뿐 아니라 병진 운동도 유발됩니다. 무게중심이나 서보에 약간의 정렬 불량이 있으면 시스템은 시간이 지남에 따라 서서히 드리프트하게 됩니다.

앞서 언급했듯이, XY 제어기는 속도를 위한 내부 PID 제어기와 위치를 위한 외부 P 제어기로 나뉩니다. 이 구조는 내부 제어기가 적분(I) 게인을 통해 체계적인 기계적 오프셋을 신속하게 흡수하도록 하는 동시에, 외부 위치 루프의 비례(P) 게인이 독립적으로 조정될 수 있게 합니다.
### **적분 와인드업 방지 메커니즘**
제어 아키텍처가 (위치 → 속도 → 자세) 캐스케이드 방식이기 때문에, 한 가지 중요한 문제가 발생합니다: 바로 적분 와인드업(integral windup)입니다. 드론이 강하게 밀려 서보가 물리적 최대 각도(포화)에 도달하면, 위치 및 속도 오차는 계속 커지게 되는데, 이는 드론이 더 이상 물리적으로 기울어져 이를 보정할 수 없기 때문입니다. 안전장치가 없다면, 속도 루프의 적분항이 비현실적으로 거대한 오차 값을 누적하게 될 것입니다. 드론이 (제약에서) 벗어나는 순간, 이 거대한 적분값은 드론이 반대 방향으로 격렬하게 튕겨 나가도록 만들 것입니다.

이를 해결하기 위해 펌웨어는 `freertos.c`에 지능형 **적분 와인드업 방지 메커니즘**을 구현합니다. 시스템은 다운스트림 출력(서보 각도 및 모터 추력)을 지속적으로 모니터링합니다. LQR 자세 제어기가 최대 허용 한계에 도달하면, 신호가 상위 체인으로 전달되어 속도 PID 제어기가 적분 누적기를 *동결*시키도록 합니다. 적분값은 시스템이 그것에 대해 실제로 작용할 수 있는 물리적 권한을 가지고 있을 때에만 증가하도록 허용됩니다.
### **LQR 서보 매핑**
LQR 출력 벡터($u$)는 정규화된 제어 노력값을 생성합니다. 이 값들은 하드웨어에 직접 쓸 수 없습니다. 대신, 혼합 행렬을 통해 두 짐벌 서보와 두 브러시리스 모터를 위한 특정 PWM 신호로 변환됩니다.
- 기준 오프셋(`LQR_SSO = 50`): 서보의 중립적인 직립 위치는 작동 범위의 50%로 정의됩니다. LQR 피치 및 롤 노력값은 이 기준 오프셋에서 스케일링되어 동적으로 더해지거나 빼집니다.
- 차동 추력: 드론에는 물리적인 요 서보가 없기 때문에, LQR 요 노력값($u_2$)은 추력 차동으로 매핑됩니다. 양의 요 명령은 모터1에 추력을 더하는 동시에 모터2에서 동일하게 빼서, 총 고도 양력에 영향을 주지 않으면서 회전 토크를 생성합니다.
# 센서 퓨전

제어 시스템에서 가장 중요한 부분은 센서입니다. 시스템이 자신이 어떤 상태에 있는지 전혀 알지 못한다면, 목표 상태로 스스로를 조종할 능력이 없습니다. 먼저 드론은 자신이 어떻게 자세를 취하고 있는지 알아야 하고, 두 번째로 자신이 어디에 위치해 있는지 알아야 합니다. PCB에는 많은 센서가 탑재되어 있으며, 커넥터를 통해 PCB에 연결되어 드론이 제대로 작동하도록 돕는 다른 센서들도 있습니다. 어떤 센서는 제한된 환경에서만 작동하고, 어떤 센서는 시간이 지남에 따라 드리프트되기 쉬우며, 또 다른 센서는 판독값에 너무 많은 노이즈가 섞여 있을 수 있습니다. 이러한 문제를 극복하기 위해서는 센서 판독값을 다양한 방식으로 융합하여 시스템의 정확한 상태를 얻어야 합니다.

### **자세 퓨전**
드론의 자세는 6축 IMU(관성 측정 장치)와 지자기 센서의 데이터로부터 유도됩니다. xioTechnologies의 fusion 라이브러리에 있는 매드윅(Madgwick) 필터가 센서 데이터를 융합하는 데 사용되었습니다. 매드윅 필터는 가속도계의 xyz 값을 사용해 중력의 방향을 추정하고, 이를 더 매끄러운 자이로스코프 판독값과 결합해 자세 값을 구합니다. 그러나 중력의 방향은 z축 방향에 관계없이 동일하기 때문에, IMU만으로는 정확한 z축 판독값을 얻을 수 없습니다. 지구 자기장의 방향을 감지하는 지자기 센서를 방위(heading)에 대한 절대 기준으로 사용해야 합니다. 매드윅 필터에 대한 보다 수학적인 설명은 여기에서 확인할 수 있습니다: https://ahrs.readthedocs.io/en/latest/filters/madgwick.html

z 위치(고도)를 얻기 위해 기압계, ToF(비행 시간) 센서, 그리고 IMU의 가속도계 값이 사용되었습니다. 기압계는 현재 위치의 대기압을 측정합니다. 대기압은 다음 공식에 따라 고도가 높아질수록 감소하므로:

$$
P = P_0 \cdot \left(1 - \frac{L \cdot h}{T_0}\right)^{\frac{g \cdot M}{R \cdot L}}
$$
$$
\frac{P}{P_0} = \left(1 - \frac{L \cdot h}{T_0}\right)^{\frac{g \cdot M}{R \cdot L}}
$$
$$
\left(\frac{P}{P_0}\right)^{\frac{R \cdot L}{g \cdot M}} = 1 - \frac{L \cdot h}{T_0}
$$
$$
\frac{L \cdot h}{T_0} = 1 - \left(\frac{P}{P_0}\right)^{\frac{R \cdot L}{g \cdot M}}
$$
$$
h(P) = \frac{T_0}{L} \cdot \left(1 - \left(\frac{P}{P_0}\right)^{\frac{R \cdot L}{g \cdot M}}\right)
$$

표준 온도($T_0$) = $288.15 \text{ K}$
기온 감률($L$) = $0.0065 \text{ K/m}$
중력 가속도($g$) = $9.80665 \text{ m/s}^2$
공기의 몰 질량($M$) = $0.0289644 \text{ kg/mol}$
기체 상수($R$) = $8.31432 \text{ J/(mol}\cdot\text{K)}$

이 값들을 대입하면 다음과 같이 됩니다:

$$
h(P) = 44330.0 \cdot \left(1.0 - \left(\frac{P}{100.0 \cdot P_0}\right)^{\frac{1}{5.255}}\right)
$$

이를 통해 고도를 계산할 수 있습니다.

ToF 센서는 지면 위 최대 2m까지의 제한된 범위를 가지지만 훨씬 더 정확한 고도 값을 제공합니다. 이 센서는 빛이 지면까지 왕복하는 데 걸리는 시간을 이용해 고도를 계산합니다. ToF 센서는 드론에 물리적으로 부착되어 있기 때문에 드론과 함께 기울어지며, 이로 인해 실제보다 더 큰 고도값이 측정됩니다. 이는 판독값을 x, y 자세각의 코사인 값으로 스케일링하여 보정할 수 있습니다.
### **고도 퓨전**
절대 Z축에 대한 선형 가속도, 기압계에서 유도된 고도, 그리고 보정된 ToF 센서의 고도 판독값은 칼만 필터를 사용하여 융합됩니다.

- **2미터 이하(ToF 범위 내)**: ToF 센서는 밀리미터 수준의 정밀도 덕분에 절대적인 기준으로 작동합니다. 이 단계에서 칼만 필터는 ToF를 크게 신뢰하며, 동시에 ToF 판독값을 이용해 기압계의 지면 오프셋을 지속적으로 재보정합니다.
- **2미터 초과(ToF 범위 밖)**: 드론이 2m 임계값을 초과하면 ToF 판독값은 신뢰할 수 없게 됩니다. 칼만 필터는 주 고도 추정을 기압계로 넘깁니다. 2m 영역을 벗어나기 직전에 기압계가 재보정되었기 때문에, 이 전환은 추정 고도의 급격한 변화 없이 매끄럽게 이루어집니다.
### **속도 퓨전**
X, Y 속도는 광류 센서(PMW3901)로 감지되며 위치 값으로 적분됩니다. 광류 센서는 지면의 패턴을 추적하여 각속도를 출력합니다.

광류 센서는 드론 몸체에 물리적으로 장착되어 있기 때문에, 드론이 기울어지기만 해도 표면 패턴에 잘못된 변화가 있는 것처럼 감지됩니다. 따라서 자이로스코프 자세 판독값으로부터 얻은 각속도를 광류 판독값에서 빼야 합니다. 또 다른 효과는 시차(parallax)로, 가까운 물체는 멀리 있는 물체보다 더 빠르게 움직이는 것처럼 보입니다. 원시 판독값은 현재 추정 고도를 기반으로 스케일링되어 실제 속도를 구합니다. 이후 이는 각 축에 대해 칼만 필터를 이용해 가속도계 값과 융합됩니다.

### **저역 통과 필터**
다음과 같은 형태의 이산 저역 통과 필터가

$$y_{n} = \alpha \cdot y_{n-1} + (1 - \alpha) \cdot x_{n}$$

노이즈를 걸러내기 위해 적절한 곳에 사용되었습니다.

### **센서 보정**
센서는 정렬 불량이나 오프셋을 보정하기 위해 사용 전에 반드시 보정되어야 합니다. 지자기 센서는 MotionCal 애플리케이션을 사용해 3x3 보정 행렬을 도출함으로써 연철(soft iron) 오차와 경철(hard iron) 오차 모두에 대해 보정되었습니다. 그리고 가속도계는 PCB 장착 오프셋과 센서 고유의 정렬 불량을 보정하기 위해 사전 보정되어 있습니다. 자이로스코프는 드론에 전원이 들어올 때마다 시작 시퀀스 초반에 보정됩니다.

# 통신

드론은 LoRa RF 모듈을 이용해 수신기와 통신합니다. 구체적으로, 데이터, 원격 측정값, 비행 명령을 장거리로 송수신하기 위해 드론에 하나, 지상국에 하나, 총 두 개의 **Ebyte E220-900T22D** 모듈이 사용됩니다.

<div align="center">
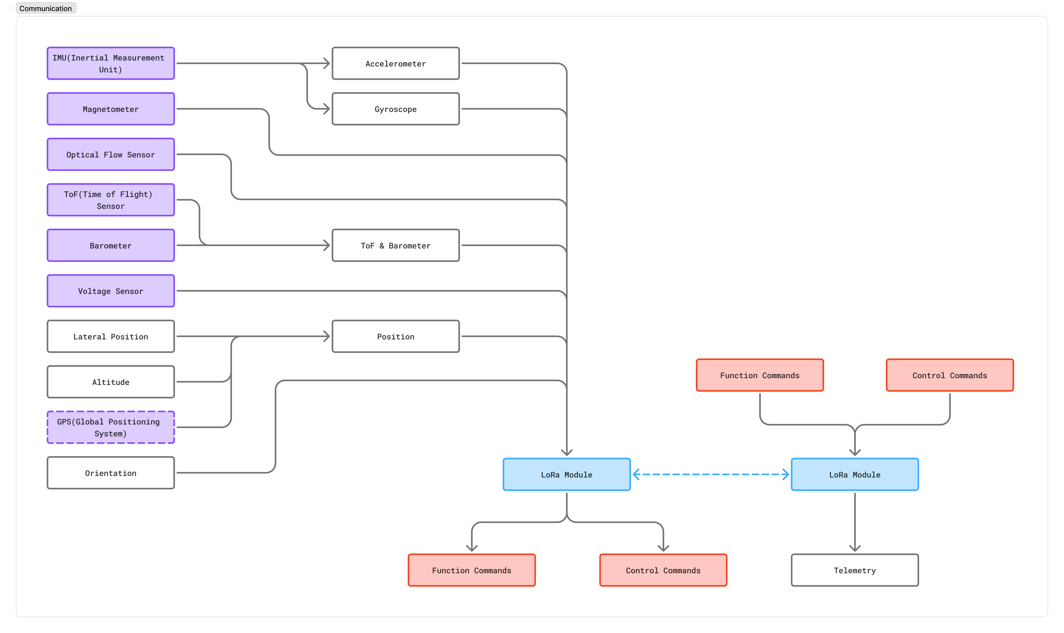
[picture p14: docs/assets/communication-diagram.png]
	
</div>

### **LoRa 구성**

지역별 주파수 규정(예: 한국은 920.9~923.3 MHz를 허용)을 준수하고 도달 거리를 최적화하기 위해, Ebyte 모듈은 다음과 같은 파라미터로 구성됩니다:

| 설정 | 값 | 설명 |
| ---|---| ---|
| 중심 주파수 | 922 MHz | 합법적인 운용 대역 |
| 에어 데이터 레이트 | 19.2 kHz  | 처리량과 전송 거리 간의 균형 |
| 보드레이트 | 115200 | 모듈과 MCU 간 UART 속도 |
| 패리티 비트 | 8N1 | 8비트 데이터, 패리티 없음, 정지 비트 1개 |
| 서브패킷 길이  | 200 bit | 패킷 분할용 버퍼 크기 |
| 전송 출력 | 10 dBm | 출력 강도 |
| LBT(Listen Before Talk) | 활성화 | 충돌 방지를 위해 지역 규정상 요구됨 |

설정 모드로 진입하려면 Ebyte 모듈의 M0, M1 핀을 하이(high)로 풀업해야 합니다. 설정 명령은 `command + address + length + parameters` 형식을 따릅니다.

설정해야 할 주요 레지스터는 다음과 같습니다:
- **REG0**: UART 보드레이트, 에어 데이터 레이트, 시리얼 패리티 비트.
- **REG1**: 서브패킷 길이, 전송 출력.
- **REG2**: 채널 주파수(850.125 + REG2 MHz).
### **비대칭 통신 프로토콜**

<div align="center">
	
</div>

표준 패킷 기반 네트워킹을 느슨하게 본떠 만든 커스텀 통신 프로토콜이 연결을 견고하게 하고 오버헤드를 최소화하기 위해 구현되었습니다.

통신 아키텍처는 비대칭적입니다:
1.  드론 → GCS(다운링크): 드론에서 GCS로 전송되는 원격 측정 데이터는 높은 처리량과 신뢰성을 요구합니다. 이는 커스텀 바이너리 프로토콜을 따르며, 촘촘하게 압축된 센서 판독값과 상태 플래그를 패킷 크기를 최소화하기 위해 원시 바이너리로 전송합니다.
2.  GCS → 드론(업링크): GCS에서 드론으로 전송되는 명령(예: 시동, 시동 해제, 보정)은 빈도가 낮으며 단순히 표준 UTF-8 문자열 형식을 사용합니다.
### **패킷 구조**

<div align="center">
	
</div>

다운링크 원격 측정 프로토콜은 통신 오버헤드를 줄이기 위해 최소한의 3바이트 헤더로 설계되었으며, 이를 통해 19.2 kHz 에어 데이터 레이트가 구조적인 패딩이 아닌 실제 센서 데이터에 완전히 활용되도록 합니다.

# FreeRTOS
드론 펌웨어는 FreeRTOS를 사용하여 여러 동시 작업을 관리하며, (자세 제어와 같은) 엄격한 실시간 요구사항이 (로그 저장이나 무선 패킷 수신과 같은) 덜 중요하고 느린 작업에 의해 절대 차단되지 않도록 보장합니다.

시스템은 우선순위에 따라 다음과 같은 주요 작업들로 나뉩니다:
1.  `controlTask`(실시간 우선순위): 드론의 절대적인 핵심입니다. (CPU 차단을 방지하기 위해 DMA를 통한) 모든 센서 폴링을 처리하고, 칼만 필터를 실행하며, LQR 행렬을 실행하고, PWM 출력을 명령합니다.
    - 실행 주기: 기본 작업은 자세 내부 루프를 계산하기 위해 100Hz로 트리거됩니다.
    - 속도 데시메이션: 중간 속도 PID 루프는 `decimation_factor = 5`를 사용하여, 20Hz(자세 사이클 5회당 한 번)로만 실행됩니다.
    - 위치 데시메이션: 외부 위치 P 루프는 `decimation_factor = 10`을 사용하여, 10Hz(자세 사이클 10회당 한 번)로 실행됩니다. 이러한 엄격한 데시메이션은 캐스케이드 루프 전반에 걸쳐 대역폭 분리를 강제합니다.
2.  `commandTask`(높은 우선순위): 지상국으로부터 수신되는 LoRa 패킷을 처리합니다. FreeRTOS 뮤텍스를 통해 안전하게 전역 기준 목표값(롤, 피치, 요, Z-고도)을 갱신합니다.
3.  `loggerTask`(보통보다 높은 우선순위): 상태 데이터를 가변 필드 비트마스크 형식으로 압축하여 SPI 플래시에 기록합니다.
4. `telemetryTask`(보통 우선순위): 기본 원격 측정 패킷(배터리 전압, 고도, 드론 상태)을 형식화하여 지상국으로의 LoRa 전송을 위해 큐에 넣습니다.
5.  `transferTask`(실시간 우선순위 - 지상에서만): 이 작업은 비행 중에는 완전히 휴면 상태로 유지됩니다. 드론이 "KILL" 명령을 수신했을 때만 활성화됩니다. 활성화되면 CPU를 독점하여 원시 SPI 플래시 메모리를 신속하게 읽어 SD 카드에 형식화된 CSV 파일로 씁니다.

### **비행 상태**
펌웨어는 안전을 보장하고 지상에서의 제어 와인드업을 방지하기 위해 엄격한 상태 기계에 의존합니다:
1. **INIT(초기화)**: 부저, 서보, 모터, 센서를 테스트하기 위해 `sys_check()`를 실행합니다.
2. **DISARMED(시동 해제)**: 드론이 대기 상태입니다. 센서는 작동하지만 제어 루프는 우회되며 모터는 0으로 고정됩니다. 적분값은 0으로 유지됩니다.
3. **ARMED(시동)**: 모터가 공회전 속도까지 회전합니다. 제어 루프가 작동하여 현재 위치를 유지합니다.
4. **LAUNCH(발사)**: Z 기준 목표값이 부드럽게 상승하며, 드론에게 상승을 명령합니다.
5. **LAND(착륙)**: Z 기준 목표값이 천천히 하강합니다. 착지가 감지되면 드론은 자동으로 시동을 해제합니다.

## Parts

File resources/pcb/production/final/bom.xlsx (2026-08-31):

Designator | Footprint | Quantity | Value | JLCPCB#
C1 | 402 | 1 | 10n | C15195
C10, C23, C54, C55 | 603 | 4 | 1u | C15849
C11, C14, C16, C2, C21, C22, C28, C29, C3, C31, C32, C35, C36, C37, C4, C40, C41, C42, C46, C47, C48, C49, C5, C51, C52, C53, C6, C8 | 402 | 28 | 100n | C45783
C12, C27, C30 | 805 | 3 | 22u | C7171
C13, C17 | CP_EIA-3216-18_Kemet-A | 2 | 10u | C1523
C15 | 402 | 1 | 1n | C3354
C18, C19, C25, C26 | C_Elec_6.3x7.7 | 4 | 470u | C1525
C20 | 603 | 1 | 6.8n | C1631
C24 | 402 | 1 | 10p | C32949
C33, C34, C38, C39, C9 | 805 | 5 | 10u | C19666
C43, C44 | 603 | 2 | 4u7 | C1548
C45, C50 | 402 | 2 | 15p | C23630
C7 | 603 | 1 | 2u2 | C15850
D1, D2, D3, D4, D5, D6 | DIO_TPD1E05U06DPYR | 6 | TPD1E05U06DPYR | C436349
D10 | D_SOD-323 | 1 | 1N4148WS | C2128
D7 | TVS_ESDA7P60-1U1M | 1 | ESDA7P60-1U1M | C1975146
D8 | 603 | 1 | Red | C2286
D9 | 603 | 1 | Blue | C2288
FB1 | 603 | 1 | 120R | C14709
J1 | TF-01A | 1 | TF-01A | C91145
J10 | JST_PH_B6B-PH-K_1x06_P2.00mm_Vertical | 1 | Conn_GPS | C33478
J11 | JST_PH_B4B-PH-K_1x04_P2.00mm_Vertical | 1 | Conn_EXT2 | C2321
J12 | PinHeader_1x04_P2.54mm_Vertical | 1 | Conn_SW | C5116483
J13 | TerminalBlock_Phoenix_MKDS-1,5-2-5.08_1x02_P5.08mm_Horizontal | 1 | Battery | C89120
J14 | JST_PH_B2B-PH-K_1x02_P2.00mm_Vertical | 1 | Conn_M1 | C2319
J15 | JST_PH_B2B-PH-K_1x02_P2.00mm_Vertical | 1 | Conn_M2 | C2319
J2 | JST_PH_B3B-PH-K_1x03_P2.00mm_Vertical | 1 | Conn_SV4 | C2320
J3 | JST_PH_B3B-PH-K_1x03_P2.00mm_Vertical | 1 | Conn_SV2 | C2320
J4 | USB_C_Receptacle_GCT_USB4105-xx-A_16P_TopMnt_Horizontal | 1 | USB4105-GF-A | C5184243
J5 | JST_PH_B3B-PH-K_1x03_P2.00mm_Vertical | 1 | Conn_SV1 | C2320
J6 | JST_PH_B3B-PH-K_1x03_P2.00mm_Vertical | 1 | Conn_SV3 | C2320
J7 | JST_PH_B4B-PH-K_1x04_P2.00mm_Vertical | 1 | Conn_EXT1 | C2321
J8 | JST_PH_B4B-PH-K_1x04_P2.00mm_Vertical | 1 | Conn_I2C | C2321
J9 | JST_PH_B6B-PH-K_1x06_P2.00mm_Vertical | 1 | Conn_RF | C33478
L1 | HSB-0650-4R9-M | 1 | 4u9 | C53373573
LS1 | MLT-8540 | 1 | MLT-8540 | C95300
Q1 | SOT-23 | 1 | SS8050 | C2150
R1, R3, R38, R39, R4, R5, R6 | 402 | 7 | 47k | C25792
R10, R11, R19, R21, R22, R23, R25 | 402 | 7 | 5k1 | C25905
R12, R2, R24, R27, R28, R30, R32, R33, R7 | 402 | 9 | 10k | C1203
R13, R34, R35, R36, R37 | 603 | 5 | 22 | C22809
R14 | 603 | 1 | 15k | C23102
R15 | 603 | 1 | 7k68 | C12447
R16 | 603 | 1 | 40k2 | C11702
R17, R29 | 402 | 2 | 1k | C226363
R18, R20, R26 | 402 | 3 | 23k7 | C60489
R31 | 603 | 1 | 470 | C23179
R8 | 1206 | 1 | 2m | C92124
R9 | 402 | 1 | 604k | C27013
SW1, SW2 | SW_SPST_TS-1088-xR020 | 2 | SW_SPST | C720477
U1 | QFN_BMP388_BOS | 1 | BMP388 | C54582187
U10 | LQFP-64_10x10mm_P0.5mm | 1 | STM32F722RETx | C118207
U2 | WLCSP-12_1.56x1.56mm_P0.4mm | 1 | BMM150 | C171681
U3 | LGA14_2P5X3X0P91_TDK | 1 | ICM-42688-P | C54308212
U4 | SOIC127P790X216-8N | 1 | W25Q128JVSIQ | C97521
U5 | SOT-223-3_TabPin2 | 1 | AMS1117-3.3 | C6186
U6 | VSSOP-10_3x3mm_P0.5mm | 1 | INA226 | C49851
U7 | SOT583_MP2393 | 1 | MP2393GTL-Z | C6674609
U8 | SOT-23-6 | 1 | USBLC6-2SC6 | C7519
U9 | RUX0012A | 1 | TPS2121RUXR | C485916
Y1 | SMT_MOB4SI_YXC | 1 | 25MHz | C9006

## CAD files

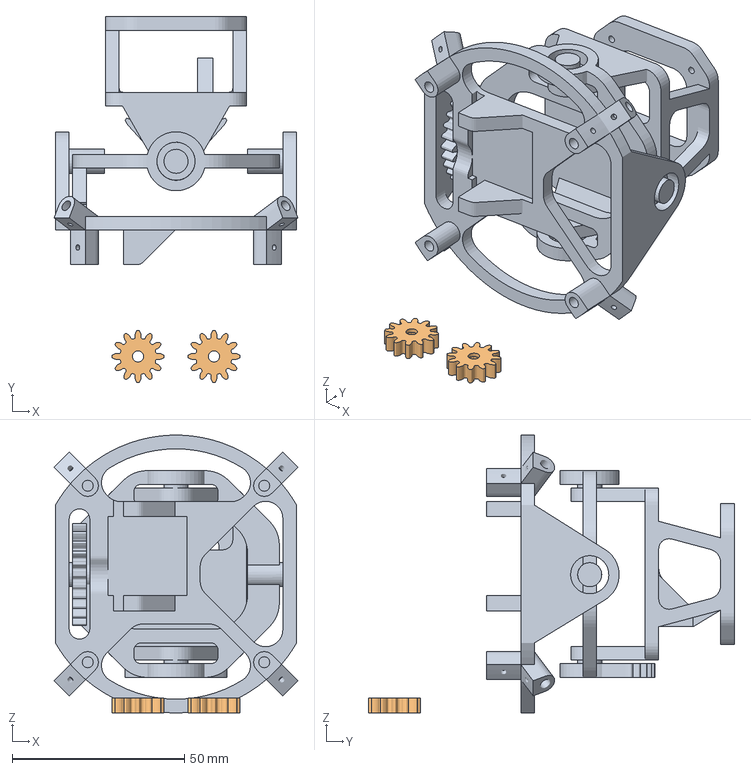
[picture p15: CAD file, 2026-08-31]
resources/3d-models/tvc.3mf
70.7 x 106.2 x 80.5 mm
tvc
Assembly

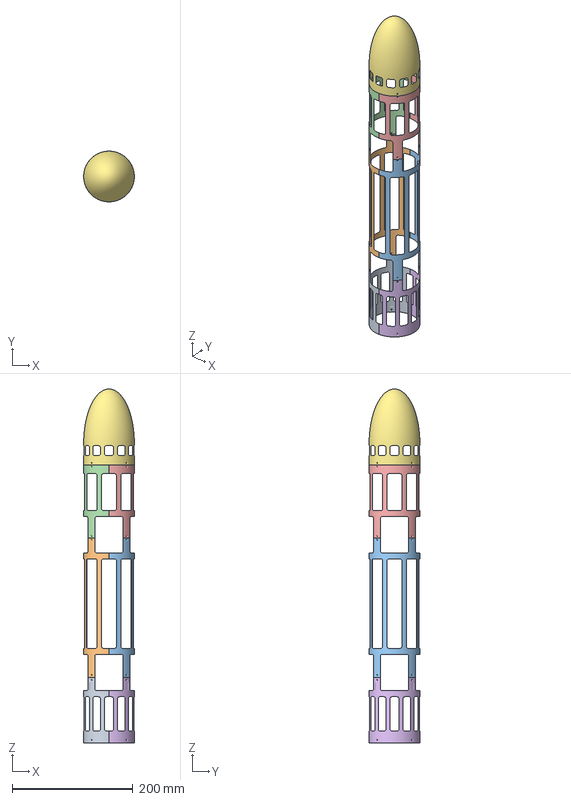
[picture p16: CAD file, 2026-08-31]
resources/3d-models/airframes.3mf
84.0 x 84.0 x 585.5 mm

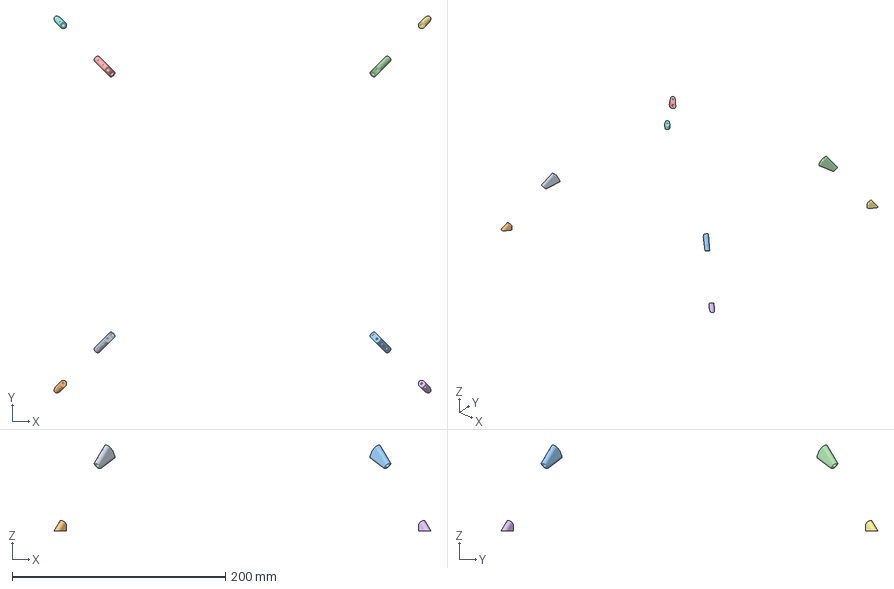
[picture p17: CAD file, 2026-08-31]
resources/3d-models/landing-gear.3mf
353.4 x 353.4 x 80.5 mm

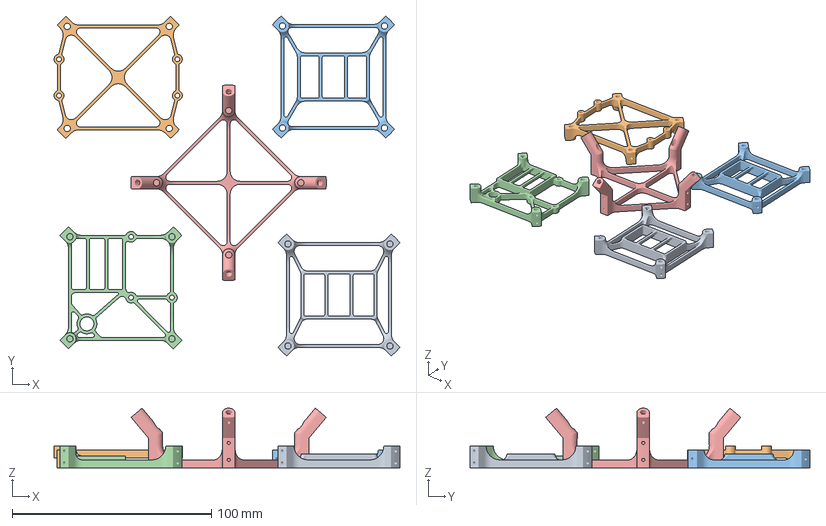
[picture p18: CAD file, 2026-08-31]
resources/3d-models/frames.3mf
173.6 x 170.6 x 30.0 mm

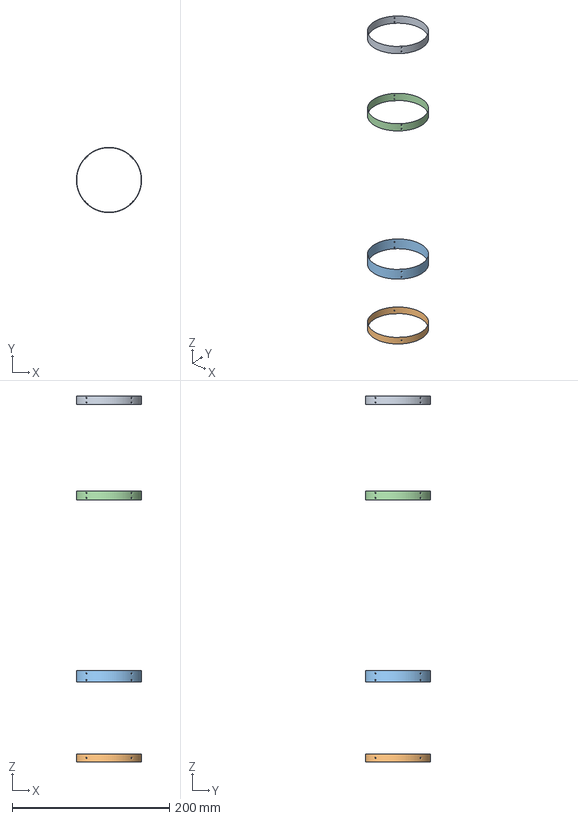
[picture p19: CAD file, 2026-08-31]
resources/3d-models/outer-frames.3mf
83.0 x 83.0 x 465.5 mm

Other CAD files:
resources/3d-models/gears.3mf
resources/3d-models/final.f3z

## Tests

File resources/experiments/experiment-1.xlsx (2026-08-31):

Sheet: test1
timestep | PWM | thrust
0 | 1000 | -2.739
1 | 1000 | -2.737
2 | 1000 | -2.674
3 | 1000 | -2.653
4 | 1000 | -2.603
5 | 1000 | -2.623
6 | 1000 | -2.656
7 | 1000 | -2.644
8 | 1000 | -2.661
9 | 1000 | -2.625
10 | 1010 | -2.607
11 | 1010 | -2.598
12 | 1010 | -2.609
13 | 1010 | -2.629
14 | 1010 | -2.688
15 | 1010 | -2.671
16 | 1010 | -2.676
17 | 1010 | -2.625
18 | 1010 | -2.662
19 | 1010 | -2.642
20 | 1020 | -2.691
21 | 1020 | -2.638
22 | 1020 | -2.494
23 | 1020 | -1.508
24 | 1020 | 0.343
25 | 1020 | 1.491
26 | 1020 | 1.995
27 | 1020 | 2.014
28 | 1020 | 2.062
29 | 1020 | 2.112
30 | 1030 | 2.143
31 | 1030 | 2.228
32 | 1030 | 2.303
33 | 1030 | 2.347
34 | 1030 | 2.353
35 | 1030 | 2.473
36 | 1030 | 2.498
37 | 1030 | 2.473
38 | 1030 | 2.489
39 | 1030 | 2.517
40 | 1040 | 2.453
41 | 1040 | 2.836
42 | 1040 | 3.975
43 | 1040 | 5.192
44 | 1040 | 5.972
45 | 1040 | 6.595
46 | 1040 | 7
47 | 1040 | 7.403
48 | 1040 | 7.642
49 | 1040 | 7.862
50 | 1050 | 7.988
51 | 1050 | 8.047
52 | 1050 | 8.173
53 | 1050 | 8.245
54 | 1050 | 8.293
55 | 1050 | 8.249
56 | 1050 | 8.308
57 | 1050 | 8.346
58 | 1050 | 8.386
59 | 1050 | 8.411
60 | 1060 | 8.459
61 | 1060 | 8.817
62 | 1060 | 10.113
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

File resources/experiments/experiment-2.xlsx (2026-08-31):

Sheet: simple lqr
matrix |  |  |  |  |  |  | state vector
A = | 0 | 0 | 1 | 0 |  |  | x = | angle x
 | 0 | 0 | 0 | 1 |  |  |  | angle y
 | 0 | 0 | 0 | 0 |  |  |  | angular velocity x
 | 0 | 0 | 0 | 0 |  |  |  | angular velocity y
matrix |  |  |  |  |  |  | output vector
B = | 0 | 0 |  |  |  |  | u = | tvc x signal
 | 0 | 0 |  |  |  |  |  | tvc y signal
 | -16.73579945 | 0
 | 0 | 16.73579945
mass | 0.405 |  |  |  | angle to servo signal
moment of inertia | 0.01802468421 |  |  |  | signal of 0 to 100 maps to approx -0.18438 to +0.18438 |  |  |  | 28.64788976
thrust | 2.943 |  |  |  | signal scale | 271.1790867
length to pivot from COM | 0.205 |  |  |  | offset | 50
voltage | 10.8
instantaneous center of zero velocity(ICZV) |  |  |  | {-0.97848689f, 0.00000000f, -0.47991552f, 0.00000000f, -0.49236596f, 0.00000000f, -0.00000001f, 0.00000000f}, {0.00000000f, 0.97848691f, 0.00000000f, 0.47991552f, 0.00000000f, 0.49236596f, 0.00000000f, -0.00000000f},
x^2 = I / m
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

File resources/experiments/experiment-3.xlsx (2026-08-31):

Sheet: data
timestamp_ms | rx | ry | rz | pz | motor1 | motor2 | servox | servoy | voltage | state | drz | filtered drz | ddrz | filtered ddrz
355468 | 0.015 | -0.005 | 1.67 | -0.112 | 0 | 0 | inf | -inf | 12.333 | 3 | 0 | 0
355478 | 0.015 | -0.005 | 1.67 | -0.107 | 0 | 0 | inf | -inf | 12.331 | 3 | 0 | 0
355488 | 0.015 | -0.005 | 1.67 | -0.108 | 0 | 0 | inf | -inf | 12.329 | 3 | 0 | 0
355498 | 0.015 | -0.005 | 1.67 | -0.108 | 0 | 0 | inf | -inf | 12.329 | 3 | 0 | 0
355508 | 0.015 | -0.005 | 1.67 | -0.109 | 0 | 0 | inf | -inf | 12.329 | 3 | -0.4 | 0
355518 | 0.015 | -0.005 | 1.666 | -0.107 | 0 | 0 | inf | -inf | 12.33 | 3 | 0 | 0
355528 | 0.015 | -0.005 | 1.666 | -0.107 | 0 | 0 | inf | -inf | 12.33 | 3 | 0 | 0
355538 | 0.014 | -0.005 | 1.666 | -0.103 | 0 | 0 | inf | -inf | 12.33 | 3 | 0 | 0
355548 | 0.014 | -0.005 | 1.666 | -0.104 | 0 | 0 | inf | -inf | 12.331 | 3 | 0 | 0
355558 | 0.014 | -0.005 | 1.666 | -0.103 | 0 | 0 | inf | -inf | 12.332 | 3 | 0 | 0
355568 | 0.014 | -0.005 | 1.666 | -0.104 | 0 | 0 | inf | -inf | 12.332 | 3 | 0 | -0.03636363636
355578 | 0.014 | -0.005 | 1.666 | -0.102 | 0 | 0 | inf | -inf | 12.333 | 3 | 0 | -0.03636363636 | 0
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

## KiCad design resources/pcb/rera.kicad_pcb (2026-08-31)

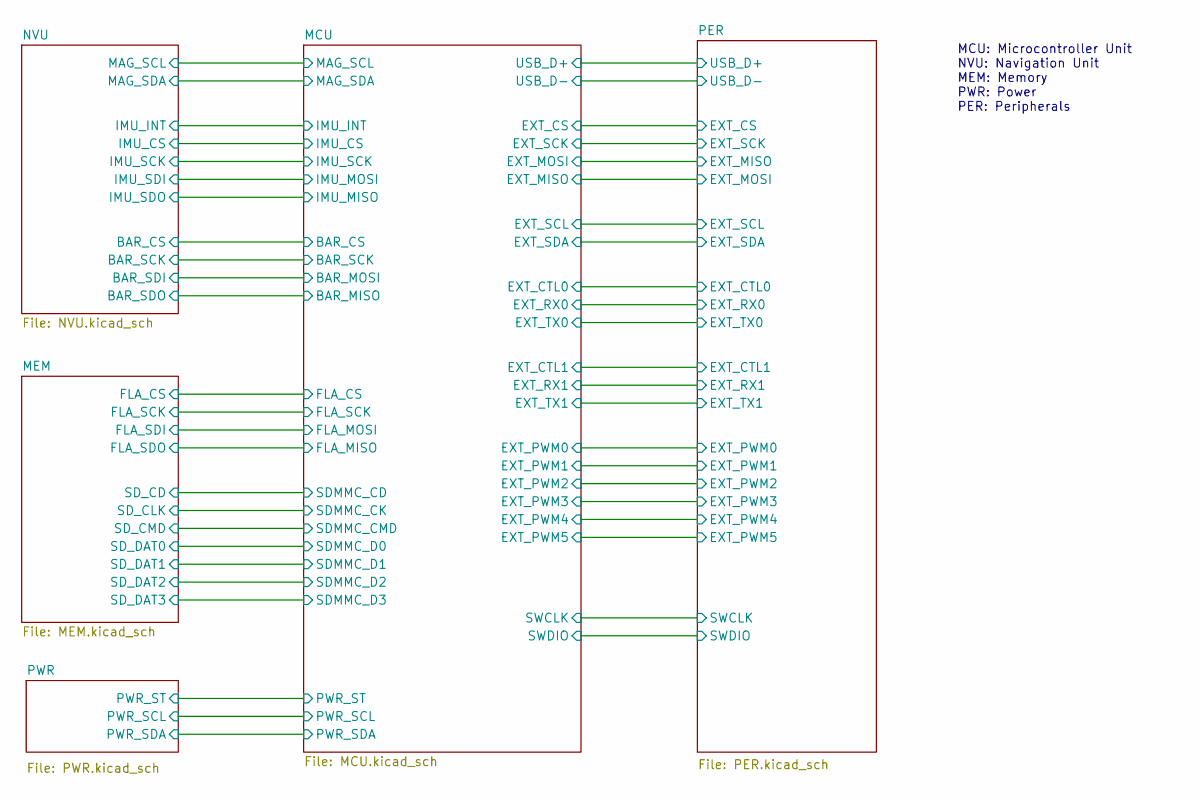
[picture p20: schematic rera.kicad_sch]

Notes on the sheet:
MCU: Microcontroller Unit NVU: Navigation Unit MEM: Memory PWR: Power PER: Peripherals

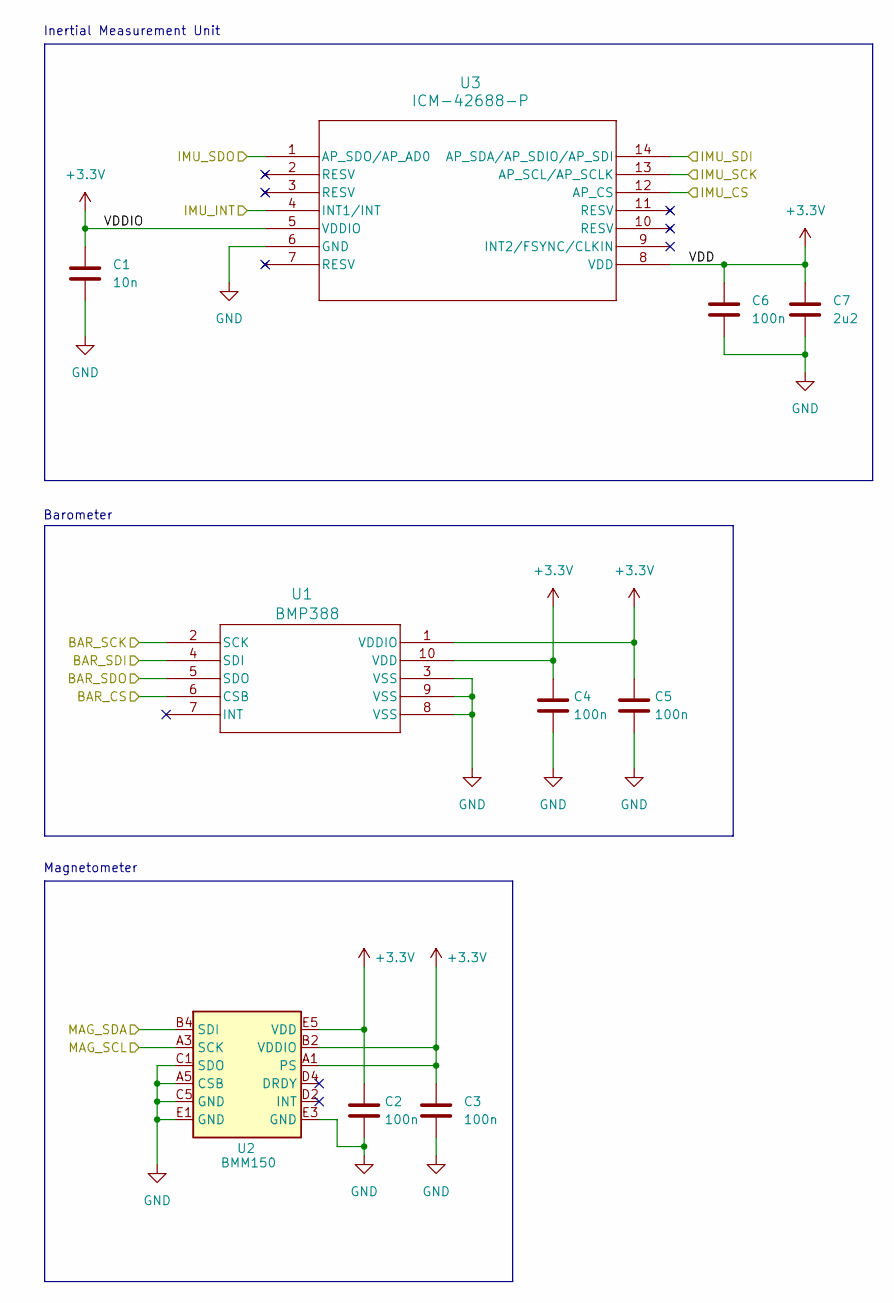
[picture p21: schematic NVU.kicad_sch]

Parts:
C1: 10n; C_0402_1005Metric
C2, C3, C4, C5, C6: 100n; C_0402_1005Metric
C7: 2u2; C_0603_1608Metric
U1: BMP388; QFN_BMP388_BOS
U2: BMM150; WLCSP-12_1.56x1.56mm_P0.4mm
U3: ICM-42688-P; LGA14_2P5X3X0P91_TDK

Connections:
+3.3V: C1.1, C2.1, C3.1, C4.1, C5.1, C6.1, C7.1, U1.1 (VDDIO), U1.10 (VDD), U2.A1 (PS), U2.B2 (VDDIO), U2.E5 (VDD), U3.5 (VDDIO), U3.8 (VDD); also elsewhere on the board
/MCU/BAR_MOSI: U1.4 (SDI); also elsewhere on the board
/MCU/BAR_SCK: U1.2 (SCK); also elsewhere on the board
/MCU/EXT_MOSI: U3.14 (AP_SDA/AP_SDIO/AP_SDI); also elsewhere on the board
/MCU/EXT_SCK: U3.13 (AP_SCL/AP_SCLK); also elsewhere on the board
/MCU/GPIO_EXTI6: U3.4 (INT1/INT); also elsewhere on the board
/MCU/I2C1_SCL: U2.A3 (SCK); also elsewhere on the board
/MCU/I2C1_SDA: U2.B4 (SDI); also elsewhere on the board
/MCU/SPI1_CS1: U1.6 (CSB); also elsewhere on the board
/MCU/SPI1_MISO: U1.5 (SDO); also elsewhere on the board
/MCU/SPI2_CS1: U3.12 (AP_CS); also elsewhere on the board
/MCU/SPI2_MISO: U3.1 (AP_SDO/AP_AD0); also elsewhere on the board
GND: C1.2, C2.2, C3.2, C4.2, C5.2, C6.2, C7.2, U1.3 (VSS), U1.8 (VSS), U1.9 (VSS), U2.A5 (CSB), U2.C1 (SDO), U2.C5 (GND), U2.E1 (GND), U2.E3 (GND), U3.6 (GND); also elsewhere on the board

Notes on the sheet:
Inertial Measurement Unit
Magnetometer
Barometer

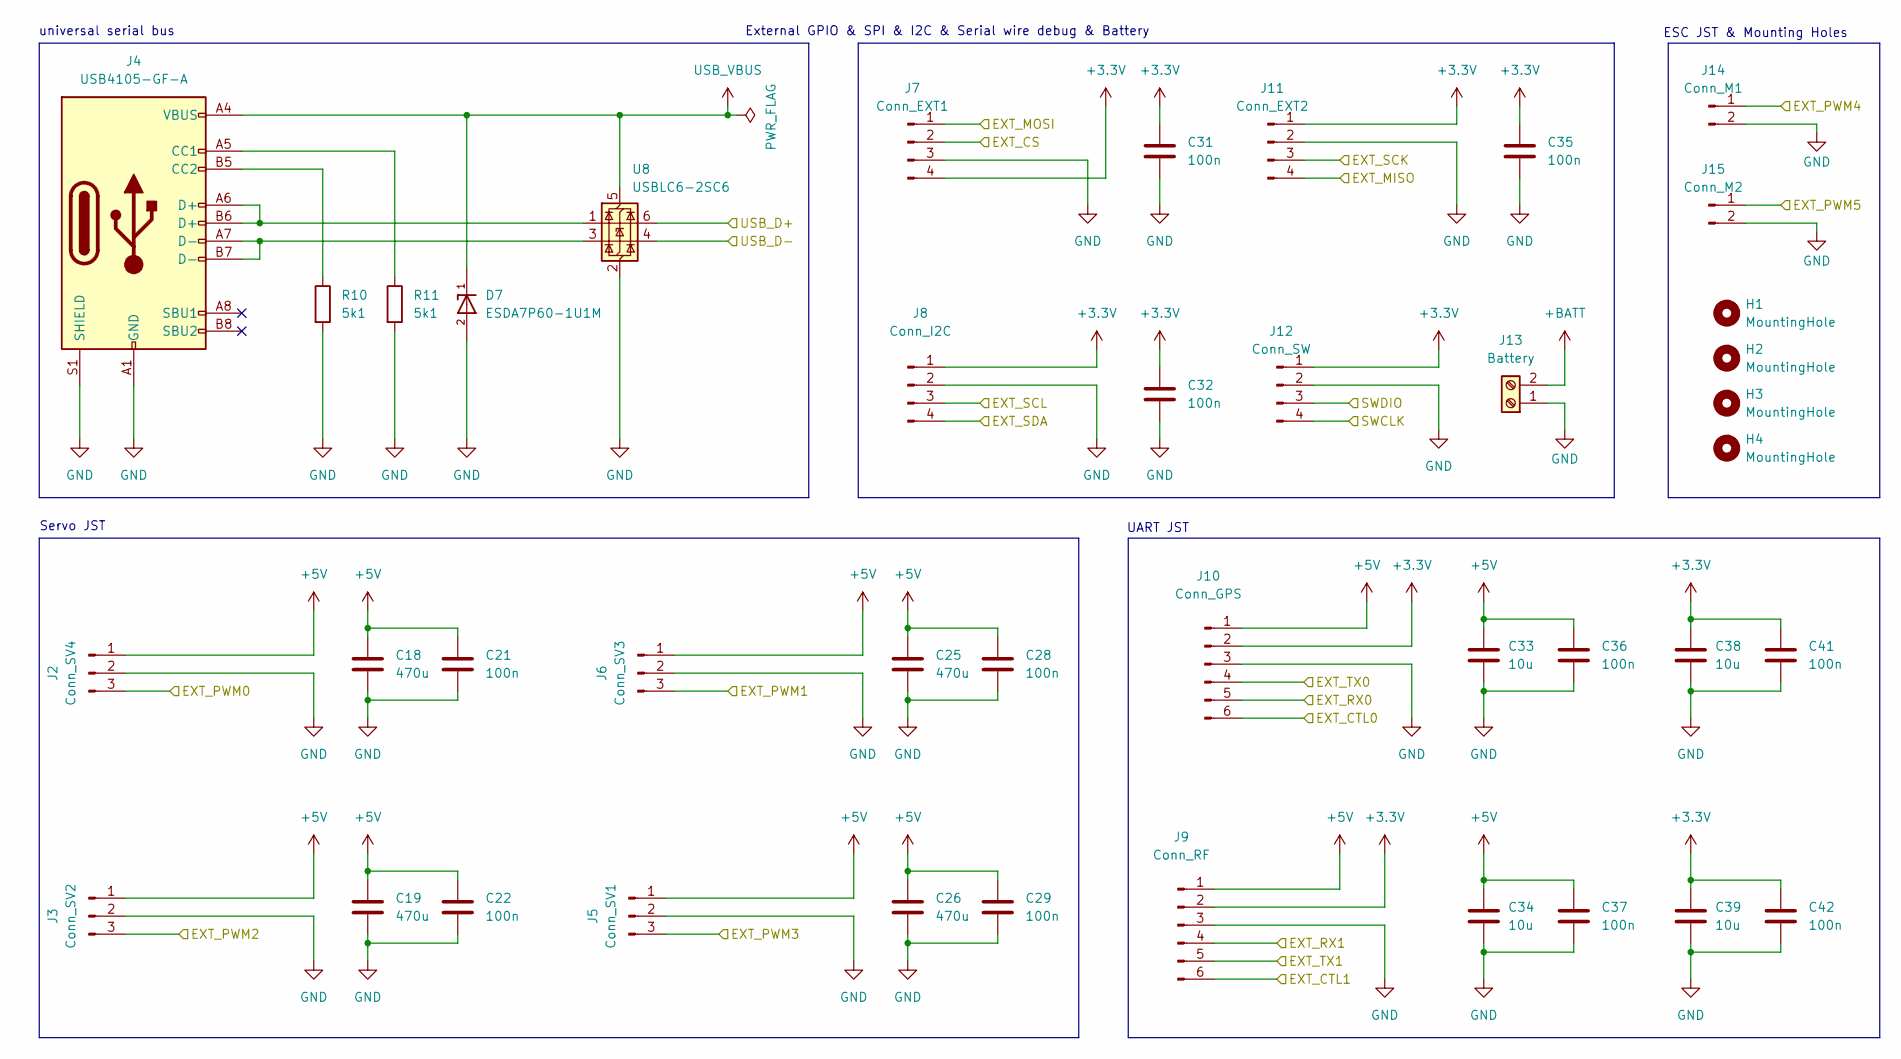
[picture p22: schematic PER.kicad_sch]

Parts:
C18, C19, C25, C26: 470u; C_Elec_6.3x7.7
C21, C22, C28, C29, C31, C32, C35, C36, C37, C41, C42: 100n; C_0402_1005Metric
C33, C34, C38, C39: 10u; C_0805_2012Metric
D7: ESDA7P60-1U1M; TVS_ESDA7P60-1U1M; PARTREV 4
H1, H2, H3, H4: MountingHole; MountingHole_3.2mm_M3
J2: Conn_SV4; JST_PH_B3B-PH-K_1x03_P2.00mm_Vertical
J3: Conn_SV2; JST_PH_B3B-PH-K_1x03_P2.00mm_Vertical
J4: USB4105-GF-A; USB_C_Receptacle_GCT_USB4105-xx-A_16P_TopMnt_Horizontal
J5: Conn_SV1; JST_PH_B3B-PH-K_1x03_P2.00mm_Vertical
J6: Conn_SV3; JST_PH_B3B-PH-K_1x03_P2.00mm_Vertical
J7: Conn_EXT1; JST_PH_B4B-PH-K_1x04_P2.00mm_Vertical
J8: Conn_I2C; JST_PH_B4B-PH-K_1x04_P2.00mm_Vertical
J9: Conn_RF; JST_PH_B6B-PH-K_1x06_P2.00mm_Vertical
J10: Conn_GPS; JST_PH_B6B-PH-K_1x06_P2.00mm_Vertical
J11: Conn_EXT2; JST_PH_B4B-PH-K_1x04_P2.00mm_Vertical
J12: Conn_SW; PinHeader_1x04_P2.54mm_Vertical
J13: Battery; TerminalBlock_Phoenix_MKDS-1,5-2-5.08_1x02_P5.08mm_Horizont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
J14: Conn_M1; JST_PH_B2B-PH-K_1x02_P2.00mm_Vertical
J15: Conn_M2; JST_PH_B2B-PH-K_1x02_P2.00mm_Vertical
R10, R11: 5k1; R_0402_1005Metric
U8: USBLC6-2SC6; SOT-23-6

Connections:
+3.3V: C31.1, C32.1, C35.1, C38.1, C39.1, C41.1, C42.1, J7.4, J8.1, J9.2, J10.2, J11.1, J12.1; also elsewhere on the board
+5V: C18.1, C19.1, C21.1, C22.1, C25.1, C26.1, C28.1, C29.1, C33.1, C34.1, C36.1, C37.1, J2.1, J3.1, J5.1, J6.1, J9.1, J10.1; also elsewhere on the board
+BATT: J13.2; also elsewhere on the board
/MCU/EXT_MOSI: J11.4; also elsewhere on the board
/MCU/EXT_SCK: J11.3; also elsewhere on the board
/MCU/GPIO_PA15: J9.6; also elsewhere on the board
/MCU/GPIO_PB3: J10.6; also elsewhere on the board
/MCU/I2C1_SCL: J8.3; also elsewhere on the board
/MCU/I2C1_SDA: J8.4; also elsewhere on the board
/MCU/SPI2_CS2: J7.2; also elsewhere on the board
/MCU/SPI2_MISO: J7.1; also elsewhere on the board
/MCU/SWCLK: J12.4; also elsewhere on the board
/MCU/SWDIO: J12.3; also elsewhere on the board
/MCU/TIM2_CH1: J14.1; also elsewhere on the board
/MCU/TIM2_CH2: J15.1; also elsewhere on the board
/MCU/TIM3_CH1: J2.3; also elsewhere on the board
/MCU/TIM3_CH2: J6.3; also elsewhere on the board
/MCU/TIM3_CH3: J3.3; also elsewhere on the board
/MCU/TIM3_CH4: J5.3; also elsewhere on the board
/MCU/UART2_RX: J10.4; also elsewhere on the board
/MCU/UART2_TX: J10.5; also elsewhere on the board
/MCU/UART3_RX: J9.5; also elsewhere on the board
/MCU/UART3_TX: J9.4; also elsewhere on the board
/MCU/USB_OTG_FS_D+: U8.6 (I/O1); also elsewhere on the board
/MCU/USB_OTG_FS_D-: U8.4 (I/O2); also elsewhere on the board
GND: C18.2, C19.2, C21.2, C22.2, C25.2, C26.2, C28.2, C29.2, C31.2, C32.2, C33.2, C34.2, C35.2, C36.2, C37.2, C38.2, C39.2, C41.2, C42.2, D7.2, J2.2, J3.2, J4.A1 (GND), J4.A12 (GND), J4.B1 (GND), J4.B12 (GND), J4.S1 (SHIELD), J5.2, J6.2, J7.3, J8.2, J9.3, J10.3, J11.2, J12.2, J13.1, J14.2, J15.2, R10.2, R11.2, U8.2 (GND); also elsewhere on the board
unnamed: J4.A5 (CC1), R11.1
unnamed: J4.B5 (CC2), R10.1
unnamed: J4.A6 (D+), J4.B6 (D+), U8.1 (I/O1)
unnamed: J4.A7 (D-), J4.B7 (D-), U8.3 (I/O2)
USB_VBUS: D7.1, J4.A4 (VBUS), J4.A9 (VBUS), J4.B4 (VBUS), J4.B9 (VBUS), U8.5 (VBUS); also elsewhere on the board

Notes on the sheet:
External GPIO & SPI & I2C & Serial wire debug & Battery
UART JST
Servo JST
ESC JST & Mounting Holes
universal serial bus

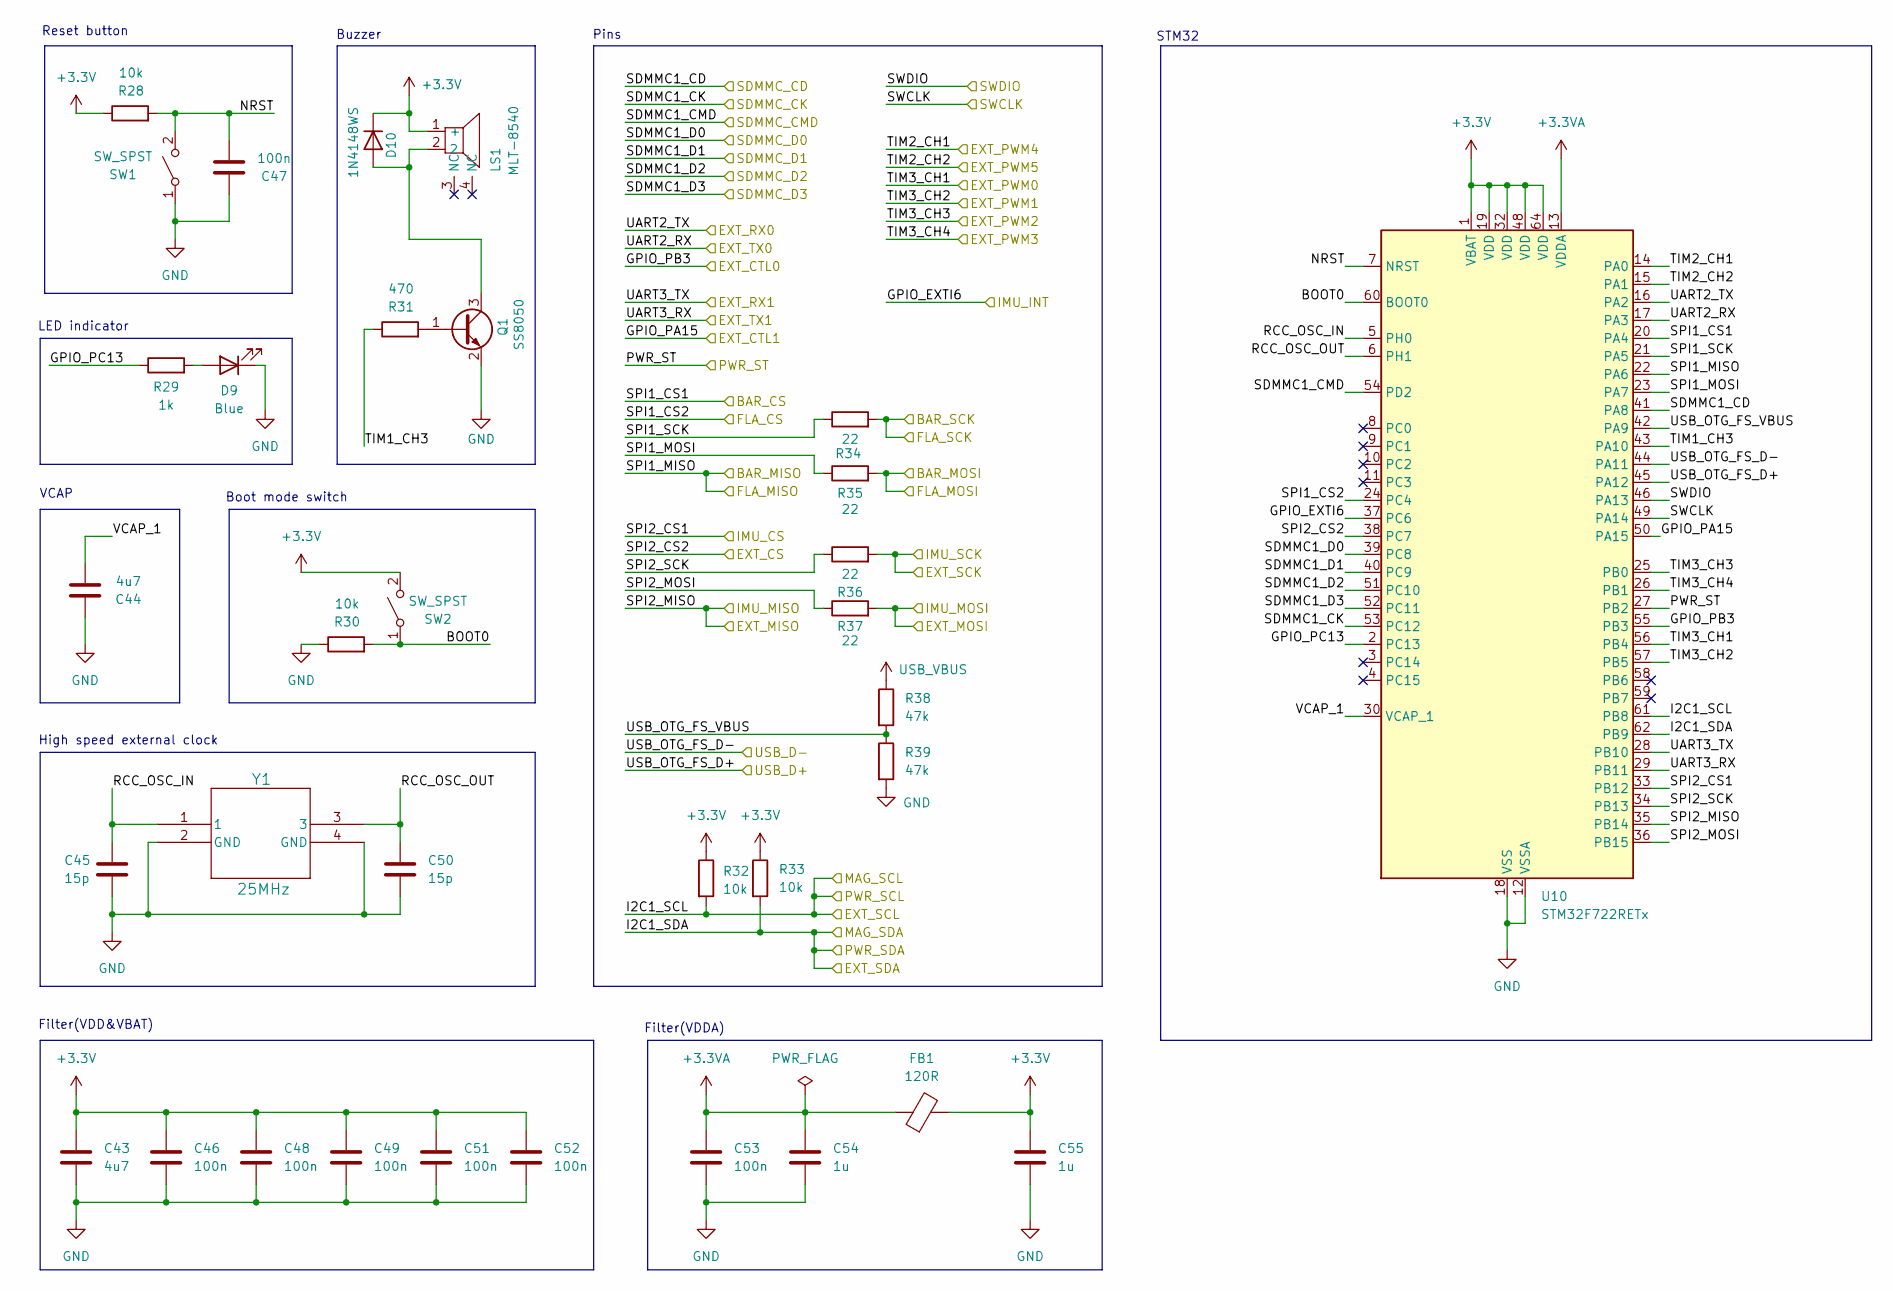
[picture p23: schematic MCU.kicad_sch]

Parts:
C43, C44: 4u7; C_0603_1608Metric
C45, C50: 15p; C_0402_1005Metric
C46, C47, C48, C49, C51, C52, C53: 100n; C_0402_1005Metric
C54, C55: 1u; C_0603_1608Metric
D9: Blue; LED_0603_1608Metric
D10: 1N4148WS; D_SOD-323
FB1: 120R; L_0603_1608Metric
LS1: MLT-8540; MPN MLT-8540; LCSC Part C95300
Q1: SS8050; SOT-23
R28, R30, R32, R33: 10k; R_0402_1005Metric
R29: 1k; R_0402_1005Metric
R31: 470; R_0603_1608Metric
R34, R35, R36, R37: 22; R_0603_1608Metric
R38, R39: 47k; R_0402_1005Metric
SW1, SW2: SW_SPST; SW_SPST_TS-1088-xR020
U10: STM32F722RETx; LQFP-64_10x10mm_P0.5mm
Y1: 25MHz; SMT_MOB4SI_YXC

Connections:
+3.3V: C43.1, C46.1, C48.1, C49.1, C51.1, C52.1, C55.1, D10.1 (K), FB1.2, LS1.1 (+), R28.1, R32.1, R33.1, SW2.2 (B), U10.1 (VBAT), U10.19 (VDD), U10.32 (VDD), U10.48 (VDD), U10.64 (VDD); also elsewhere on the board
+3.3VA: C53.1, C54.1, FB1.1, U10.13 (VDDA)
/MCU/BAR_MOSI: R35.2; also elsewhere on the board
/MCU/BAR_SCK: R34.2; also elsewhere on the board
/MCU/BOOT0: R30.2, SW2.1 (A), U10.60 (BOOT0)
/MCU/EXT_MOSI: R37.2; also elsewhere on the board
/MCU/EXT_SCK: R36.2; also elsewhere on the board
/MCU/GPIO_EXTI6: U10.37 (PC6); also elsewhere on the board
/MCU/GPIO_PA15: U10.50 (PA15); also elsewhere on the board
/MCU/GPIO_PB3: U10.55 (PB3); also elsewhere on the board
/MCU/GPIO_PC13: R29.1, U10.2 (PC13)
/MCU/I2C1_SCL: R32.2, U10.61 (PB8); also elsewhere on the board
/MCU/I2C1_SDA: R33.2, U10.62 (PB9); also elsewhere on the board
/MCU/NRST: C47.2, R28.2, SW1.2 (B), U10.7 (NRST)
/MCU/PWR_ST: U10.27 (PB2); also elsewhere on the board
/MCU/RCC_OSC_IN: C45.1, U10.5 (PH0), Y1.1
/MCU/RCC_OSC_OUT: C50.1, U10.6 (PH1), Y1.3
/MCU/SDMMC1_CD: U10.41 (PA8); also elsewhere on the board
/MCU/SDMMC1_CK: U10.53 (PC12); also elsewhere on the board
/MCU/SDMMC1_CMD: U10.54 (PD2); also elsewhere on the board
/MCU/SDMMC1_D0: U10.39 (PC8); also elsewhere on the board
/MCU/SDMMC1_D1: U10.40 (PC9); also elsewhere on the board
/MCU/SDMMC1_D2: U10.51 (PC10); also elsewhere on the board
/MCU/SDMMC1_D3: U10.52 (PC11); also elsewhere on the board
/MCU/SPI1_CS1: U10.20 (PA4); also elsewhere on the board
/MCU/SPI1_CS2: U10.24 (PC4); also elsewhere on the board
/MCU/SPI1_MISO: U10.22 (PA6); also elsewhere on the board
/MCU/SPI1_MOSI: R35.1, U10.23 (PA7)
/MCU/SPI1_SCK: R34.1, U10.21 (PA5)
/MCU/SPI2_CS1: U10.33 (PB12); also elsewhere on the board
/MCU/SPI2_CS2: U10.38 (PC7); also elsewhere on the board
/MCU/SPI2_MISO: U10.35 (PB14); also elsewhere on the board
/MCU/SPI2_MOSI: R37.1, U10.36 (PB15)
/MCU/SPI2_SCK: R36.1, U10.34 (PB13)
/MCU/SWCLK: U10.49 (PA14); also elsewhere on the board
/MCU/SWDIO: U10.46 (PA13); also elsewhere on the board
/MCU/TIM1_CH3: R31.1, U10.43 (PA10)
/MCU/TIM2_CH1: U10.14 (PA0); also elsewhere on the board
/MCU/TIM2_CH2: U10.15 (PA1); also elsewhere on the board
/MCU/TIM3_CH1: U10.56 (PB4); also elsewhere on the board
/MCU/TIM3_CH2: U10.57 (PB5); also elsewhere on the board
/MCU/TIM3_CH3: U10.25 (PB0); also elsewhere on the board
/MCU/TIM3_CH4: U10.26 (PB1); also elsewhere on the board
/MCU/UART2_RX: U10.17 (PA3); also elsewhere on the board
/MCU/UART2_TX: U10.16 (PA2); also elsewhere on the board
/MCU/UART3_RX: U10.29 (PB11); also elsewhere on the board
/MCU/UART3_TX: U10.28 (PB10); also elsewhere on the board
/MCU/USB_OTG_FS_D+: U10.45 (PA12); also elsewhere on the board
/MCU/USB_OTG_FS_D-: U10.44 (PA11); also elsewhere on the board
/MCU/USB_OTG_FS_VBUS: R38.2, R39.1, U10.42 (PA9)
/MCU/VCAP_1: C44.2, U10.30 (VCAP_1)
GND: C43.2, C44.1, C45.2, C46.2, C47.1, C48.2, C49.2, C50.2, C51.2, C52.2, C53.2, C54.2, C55.2, D9.1 (K), Q1.2 (E), R30.1, R39.2, SW1.1 (A), U10.12 (VSSA), U10.18 (VSS), U10.31 (VSS), U10.47 (VSS), U10.63 (VSS), Y1.2 (GND), Y1.4 (GND); also elsewhere on the board
unnamed: D9.2 (A), R29.2
unnamed: D10.2 (A), LS1.2, Q1.3 (C)
unnamed: Q1.1 (B), R31.2
USB_VBUS: R38.1; also elsewhere on the board

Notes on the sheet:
Pins
High speed external clock
STM32
Buzzer
Boot mode switch
Filter(VDDA)
Reset button
Filter(VDD&VBAT)
LED indicator
VCAP

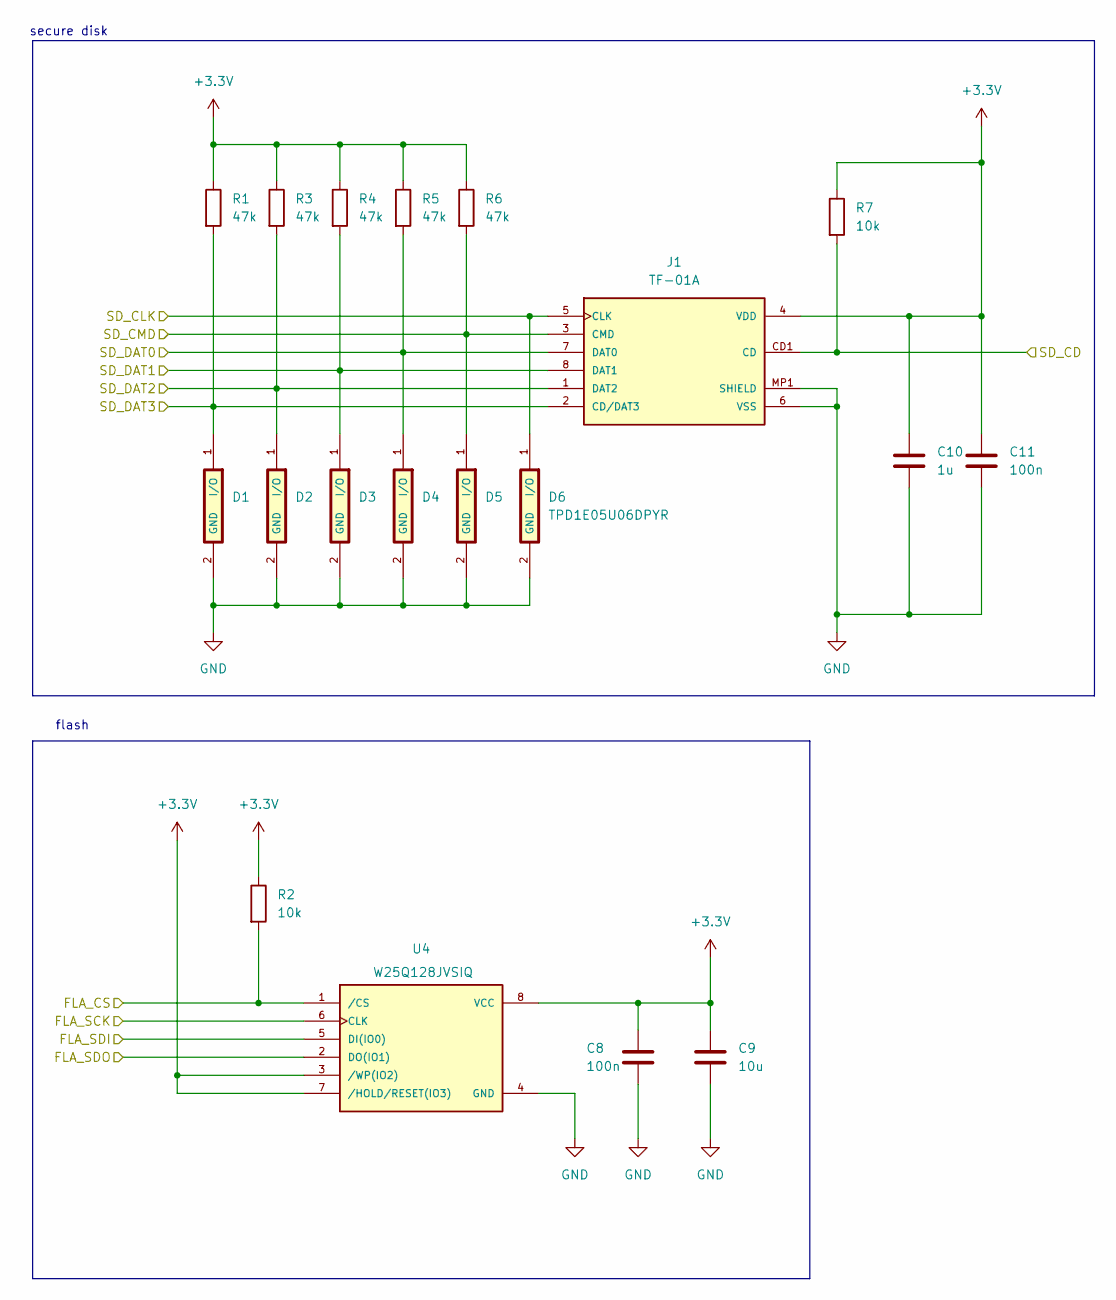
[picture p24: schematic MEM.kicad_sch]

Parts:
C8, C11: 100n; C_0402_1005Metric
C9: 10u; C_0805_2012Metric
C10: 1u; C_0603_1608Metric
D1, D2, D3, D4, D5, D6: TPD1E05U06DPYR; DIO_TPD1E05U06DPYR
J1: TF-01A
R1, R3, R4, R5, R6: 47k; R_0402_1005Metric
R2, R7: 10k; R_0402_1005Metric
U4: W25Q128JVSIQ; SOIC127P790X216-8N; PARTREV I

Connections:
+3.3V: C8.1, C9.1, C10.1, C11.1, J1.4 (VDD), R1.1, R2.1, R3.1, R4.1, R5.1, R6.1, R7.1, U4.3 (/WP(IO2)), U4.7 (/HOLD/RESET(IO3)), U4.8 (VCC); also elsewhere on the board
/MCU/BAR_MOSI: U4.5 (DI(IO0)); also elsewhere on the board
/MCU/BAR_SCK: U4.6 (CLK); also elsewhere on the board
/MCU/SDMMC1_CD: J1.CD1 (CD), R7.2; also elsewhere on the board
/MCU/SDMMC1_CK: D6.1 (I/O), J1.5 (CLK); also elsewhere on the board
/MCU/SDMMC1_CMD: D5.1 (I/O), J1.3 (CMD), R6.2; also elsewhere on the board
/MCU/SDMMC1_D0: D4.1 (I/O), J1.7 (DAT0), R5.2; also elsewhere on the board
/MCU/SDMMC1_D1: D3.1 (I/O), J1.8 (DAT1), R4.2; also elsewhere on the board
/MCU/SDMMC1_D2: D2.1 (I/O), J1.1 (DAT2), R3.2; also elsewhere on the board
/MCU/SDMMC1_D3: D1.1 (I/O), J1.2 (CD/DAT3), R1.2; also elsewhere on the board
/MCU/SPI1_CS2: R2.2, U4.1 (/CS); also elsewhere on the board
/MCU/SPI1_MISO: U4.2 (DO(IO1)); also elsewhere on the board
GND: C8.2, C9.2, C10.2, C11.2, D1.2 (GND), D2.2 (GND), D3.2 (GND), D4.2 (GND), D5.2 (GND), D6.2 (GND), J1.6 (VSS), J1.MP1 (SHIELD), J1.MP2 (SHIELD), J1.MP3 (SHIELD), J1.MP4 (SHIELD), U4.4 (GND); also elsewhere on the board

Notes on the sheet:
secure disk
flash

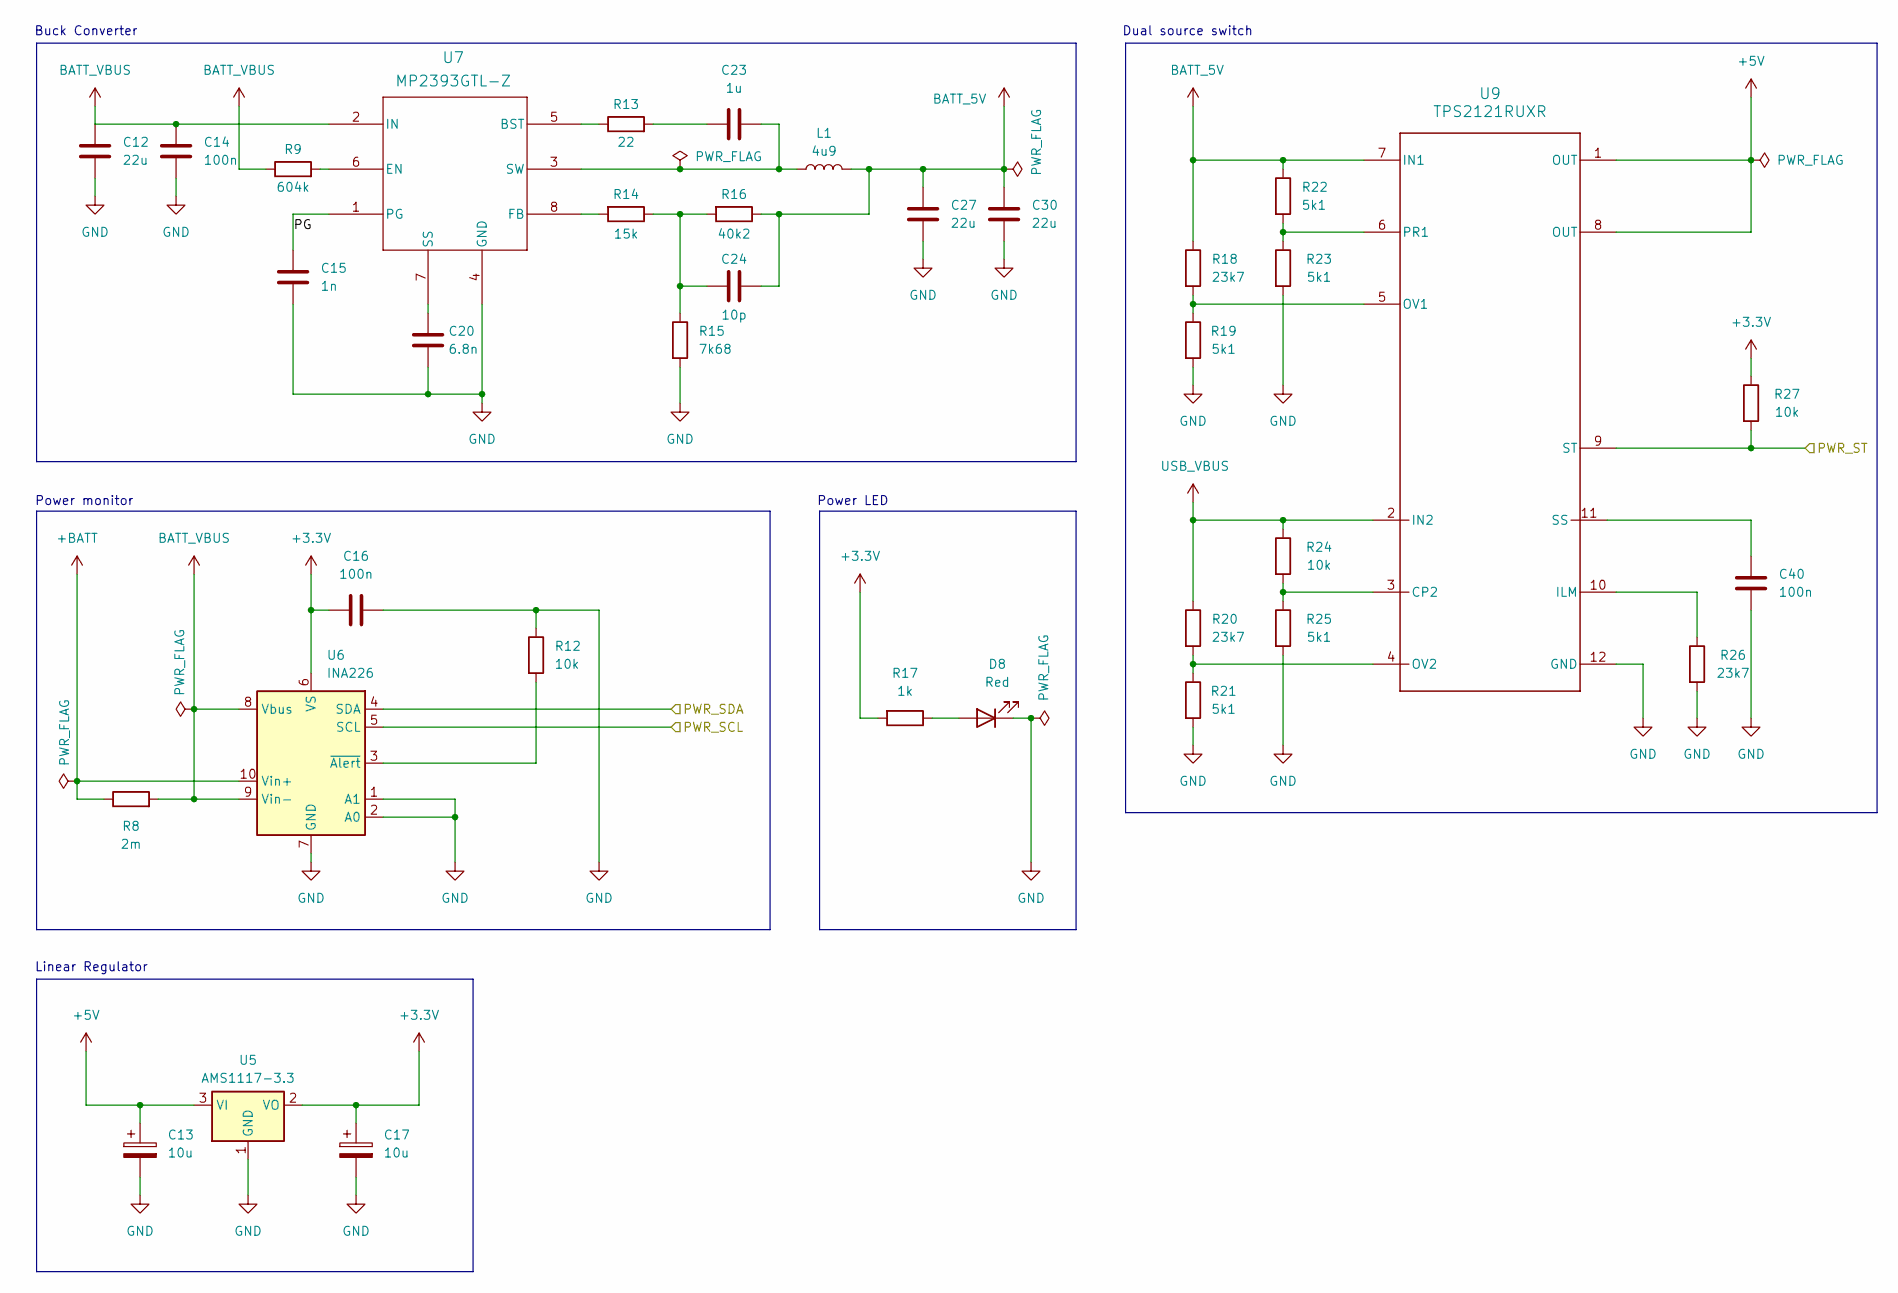
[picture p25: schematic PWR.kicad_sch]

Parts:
C12, C27, C30: 22u; C_0805_2012Metric
C13, C17: 10u; CP_EIA-3216-18_Kemet-A
C14, C16, C40: 100n; C_0402_1005Metric
C15: 1n; C_0402_1005Metric
C20: 6.8n; C_0603_1608Metric
C23: 1u; C_0603_1608Metric
C24: 10p; C_0402_1005Metric
D8: Red; LED_0603_1608Metric
L1: 4u9; HSB-0650-4R9-M
R8: 2m; R_1206_3216Metric
R9: 604k; R_0402_1005Metric
R12, R24, R27: 10k; R_0402_1005Metric
R13: 22; R_0603_1608Metric
R14: 15k; R_0603_1608Metric
R15: 7k68; R_0603_1608Metric
R16: 40k2; R_0603_1608Metric
R17: 1k; R_0402_1005Metric
R18, R20, R26: 23k7; R_0402_1005Metric
R19, R21, R22, R23, R25: 5k1; R_0402_1005Metric
U5: AMS1117-3.3; SOT-223-3_TabPin2
U6: INA226; VSSOP-10_3x3mm_P0.5mm
U7: MP2393GTL-Z; SOT583_MP2393
U9: TPS2121RUXR; RUX0012A

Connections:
+3.3V: C16.1, C17.1, R17.2, R27.1, U5.2 (VO), U6.6 (VS); also elsewhere on the board
+5V: C13.1, U5.3 (VI), U9.1 (OUT), U9.8 (OUT); also elsewhere on the board
+BATT: R8.1, U6.10 (Vin+); also elsewhere on the board
/MCU/I2C1_SCL: U6.5 (SCL); also elsewhere on the board
/MCU/I2C1_SDA: U6.4 (SDA); also elsewhere on the board
/MCU/PWR_ST: R27.2, U9.9 (ST); also elsewhere on the board
/PWR/PG: C15.2, U7.1 (PG)
BATT_5V: C24.1, C27.1, C30.1, L1.2, R16.1, R18.1, R22.1, U9.7 (IN1)
BATT_VBUS: C12.1, C14.1, R8.2, R9.1, U6.8 (Vbus), U6.9 (Vin-), U7.2 (IN)
GND: C12.2, C13.2, C14.2, C15.1, C16.2, C17.2, C20.1, C27.2, C30.2, C40.2, D8.1 (K), R12.1, R15.2, R19.2, R21.2, R23.2, R25.2, R26.2, U5.1 (GND), U6.1 (A1), U6.2 (A0), U6.7 (GND), U7.4 (GND), U9.12 (GND); also elsewhere on the board
unnamed: C23.1, R13.2
unnamed: C24.2, R14.1, R15.1, R16.2
unnamed: D8.2 (A), R17.1
unnamed: R12.2, U6.3 (~Alert)
unnamed: R13.1, U7.5 (BST)
unnamed: R9.2, U7.6 (EN)
unnamed: R14.2, U7.8 (FB)
unnamed: C20.2, U7.7 (SS)
unnamed: C23.2, L1.1, U7.3 (SW)
unnamed: R24.2, R25.1, U9.3 (CP2)
unnamed: R26.1, U9.10 (ILM)
unnamed: R18.2, R19.1, U9.5 (OV1)
unnamed: R20.2, R21.1, U9.4 (OV2)
unnamed: R22.2, R23.1, U9.6 (PR1)
unnamed: C40.1, U9.11 (SS)
USB_VBUS: R20.1, R24.1, U9.2 (IN2); also elsewhere on the board

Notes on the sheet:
Power LED
Power monitor
Linear Regulator
Buck Converter
Dual source switch

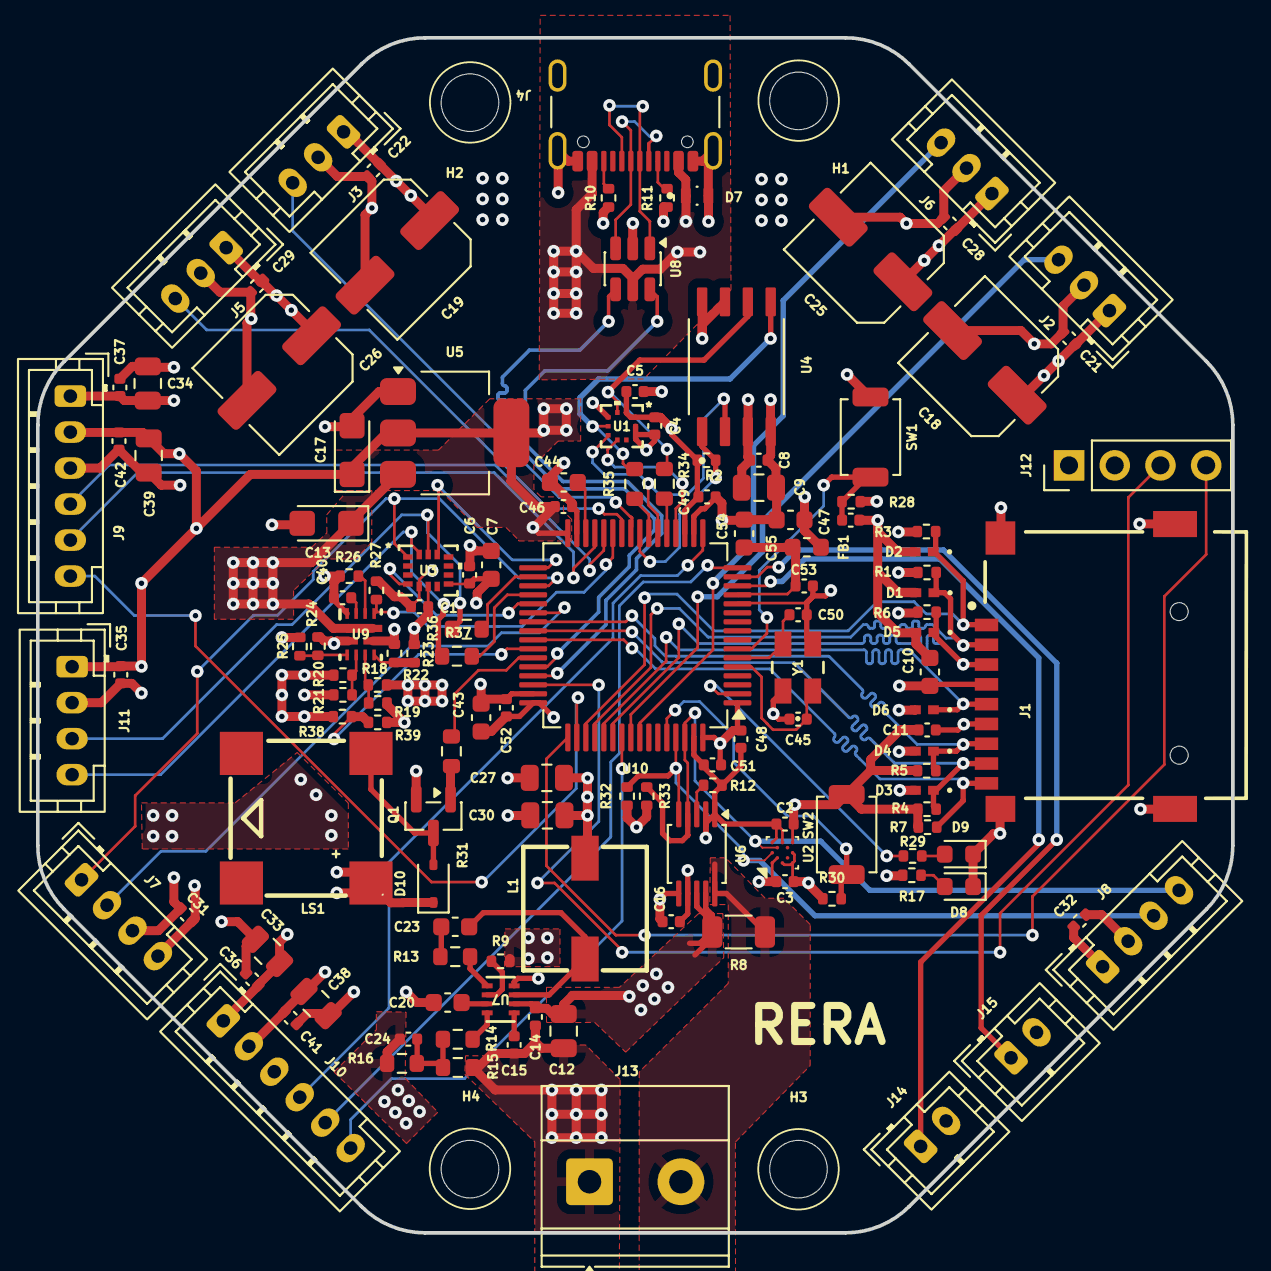
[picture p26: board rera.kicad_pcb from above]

Board: 4 copper layers, 66.4 x 66.4 mm, 140 parts (0 on the bottom side), 80 nets.

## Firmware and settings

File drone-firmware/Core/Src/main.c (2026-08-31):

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
/* Includes ------------------------------------------------------------------*/
#include "main.h"
#include "cmsis_os.h"
#include "adc.h"
#include "dma.h"
#include "fatfs.h"
#include "i2c.h"
#include "sdmmc.h"
#include "spi.h"
#include "tim.h"
#include "usart.h"
#include "usb_device.h"
#include "gpio.h"

/* USER CODE BEGIN Includes */
#include "global.h"
/* USER CODE END Includes */


/* USER CODE BEGIN PV */

#if 1 // GLOBAL VARIABLES
bmm150_data_t bmm150_data;
bmp388_data_t bmp388_data;
icm42688p_data_t icm42688p_data;
ina226_data_t ina226_data;
FATFS fs;
FIL fil;
FRESULT res;
uint8_t com_receive_buf[128] = {0};
uint8_t com_transmit_buf[128] = {0};
note_t melody[] = {
    {NOTE_C5, EIGHTH}, {NOTE_D5, EIGHTH}, {NOTE_E5, EIGHTH}, {NOTE_G5, EIGHTH},
    {NOTE_E5, EIGHTH}, {NOTE_G5, QUARTER}, {NOTE_C6, HALF},
};
uint8_t melody_len = (sizeof(melody) / sizeof(melody[0]));

FusionAhrs ahrs;
FusionBias bias;
FusionMatrix gyro_misalignment = {{1.0f, 0.0f, 0.0f, 0.0f, 1.0f, 0.0f, 0.0f, 0.0f, 1.0f}};
FusionVector gyro_sensitivity = {{1.0f, 1.0f, 1.0f}};
FusionVector gyro_offset = {{0.0f, 0.0f, 0.0f}};
FusionMatrix accel_misalignement = {{1.0f, 0.0f, 0.0f, 0.0f, 1.0f, 0.0f, 0.0f, 0.0f, 1.0f}};
FusionVector accel_sensitivity = {{1.0f, 1.0f, 1.0f}};
FusionVector accel_offset = {{0.0f, 0.0f, 0.0f}};
FusionMatrix mag_softIronMatrix = {{0.940f, 0.041f, 0.0f, 0.041f, 1.027f, 0.006f, 0.0f, 0.006f, 1.047f}};
FusionVector mag_hardIronOffset = {{-7.37f, 3.12f, 16.56f}};

FusionAhrsSettings settings = {
	.convention = FusionConventionNed,
	.gain = 0.5f,
	.gyroscopeRange = 500.0f,
	.accelerationRejection = 8.0f,
	.magneticRejection = 10.0f,
};
FusionVector gyro;
FusionVector accel;
FusionVector mag;
FusionEuler ori;
FusionVector lin_accel;
FusionVector vel = {{0, 0, 0}};
FusionVector pos = {{0, 0, 0}};

kalman_t kf_altitude;
float altitude_offset = 0;

lpf_t lpf_altitude;
lpf_t lpf_voltage;
lpf_t lpf_velx;
lpf_t lpf_vely;

lqr_t lqr;
float u_min[] = {-0.149066f, -0.149066f, -0.1, -HOVER_THRUST};
float u_max[] = { 0.149066f,  0.149066f, 0.1, 0.05f * G};
float x_ref[] = {0.0f, 0.0f, 0.0f, 0.0f, 0.0f, 0.0f, 0.0f, 0.0f, 0.0f, 0.0f, 0.0f, 0.0f};
float cmd_ref[] = {0.0f, 0.0f, 0.0f};
float pz_integral = 0;
float rx_integral = 0;
float ry_integral = 0;
float rz_integral = 0;
float rz_offset = 0;
float rz_prev_wrapped = 0.0f;
float rz_unwrapped = 0.0f;
volatile bool rz_unwrap_init = false;
volatile bool dt_init = false;

float ref_rx_offset = -4.0f; // hard coded offsets
float ref_ry_offset = 7.0f;  // hard coded offsets
float ref_rz_offset = 0;
float ref_pz_offset = 0;

volatile spi2_pending_t spi2_pending = SPI2_PENDING_NONE;
volatile i2c1_pending_t i2c1_pending = I2C1_PENDING_NONE;

drone_state_t drone_state = DRONE_DISARMED;

uint32_t flash_write_address = 0x000000;
uint32_t flash_max_address = 0x1000000;
#endif // GLOBAL VARIABLES

#if 1 // LOCAL VARIABLES
uint16_t flash_buf_idx = 0;
uint8_t  flash_page_buffer[256];
const float K[LQR_MAX_INPUTS][LQR_MAX_STATES] = {
    {-1.14198845f, 0.00000000f, 0.00000000f, 0.00000000f, -0.29207114f, 0.00000000f, 0.00000000f, 0.00000000f, -0.29505944f, 0.00000000f, 0.00000000f, 0.00000000f},
    {0.00000000f, 1.14198845f, 0.00000000f, 0.00000000f, 0.00000000f, 0.29207114f, 0.00000000f, 0.00000000f, 0.00000000f, 0.29505944f, 0.00000000f, 0.00000000f},
    {0.00000000f, 0.00000000f, 0.06454058f, 0.00000000f, 0.00000000f, 0.00000000f, 0.57378372f, 0.00000000f, 0.00000000f, 0.00000000f, 0.00238777f, 0.00000000f},
	{0.00000000f, 0.00000000f, 0.00000000f, 1.73874813f, 0.00000000f, 0.00000000f, 0.00000000f, 1.23067720f, 0.00000000f, 0.00000000f, 0.00000000f, 0.04408133f},
};
float  Q[] = {0.05f, // acceleration
             0.1f, // velocity
             0.3f}; // position

float R[] = {0.15f, // imu noise
             0.15f, // barometer noise
			 0.005f}; // tof noise


kalman_t kf_vel_x;
kalman_t kf_vel_y;

float Q_vel[] = {0.05f,  // acceleration — reused from kf_altitude's tuning, same physical sensor
                  0.5f}; // velocity

float R_vel[] = {0.15f, // accelerometer noise
                  0.001f}; // optical flow sensor noise

float x0_vel[] = {0.0f, 0.0f};

pid_t vel_pid_x = {
	.kp =  -0.140f,
	.ki = -0.040f,
	.kd = -0.008f,
	.output_min = -0.2f,
	.output_max =  0.2f,
	.integral_min = -2.5f,
	.integral_max =  2.5f,
	.d_filter_alpha = 0.1f,
	.decimation_factor = 5, // division factor from the P and I update loop to the output loop
};
pid_t vel_pid_y = {
	.kp =  0.140f,
	.ki = 0.040f,
	.kd = 0.008f,
	.output_min = -0.2f,
	.output_max =  0.2f,
	.integral_min = -2.5f,
	.integral_max =  2.5f,
	.d_filter_alpha = 0.1f,
	.decimation_factor = 5,
};
pid_t pos_p_x = {
	.kp =  0.5f,
	.output_min = -0.5f,
	.output_max =  0.5f,
	.decimation_factor = 10, // division factor from the P and I update loop to the output loop
};

pid_t pos_p_y = {
	.kp =  0.5f,
	.output_min = -0.5f,
	.output_max =  0.5f,
	.decimation_factor = 10,
};
float x0[] = {0.0f, 0.0f, 0.0f};
#endif // LOCAL VARIABLES

#if 1 // DRIVER CONFIG
pmw3901_data_t pmw3901_data;
pmw3901_config_t pmw3901_conf = {
    .hspi    = &hspi2,
    .cs_port = SPI2_CS2_GPIO_Port,
    .cs_pin  = SPI2_CS2_Pin,
};

uint16_t vl53l1x_dev = 0x52;
servo_config_t servox_conf = {
	.pwm_timer = &htim3,
	.pwm_channel = TIM_CHANNEL_1,
	.offset = 25,
};
servo_config_t servoy_conf = {
	.pwm_timer = &htim3,
	.pwm_channel = TIM_CHANNEL_4,
	.offset = 20,
};
motor_config_t motor1_conf = {
	.pwm_timer = &htim2,
	.pwm_channel = TIM_CHANNEL_1,
};
motor_config_t motor2_conf = {
	.pwm_timer = &htim2,
	.pwm_channel = TIM_CHANNEL_2,
};
bmm150_config_t bmm150_conf = {
	.iface    = BMM150_IFACE_I2C,
	.hi2c     = &hi2c1,
	.i2c_addr = BMM150_I2C_ADDR_ALT3,
	.hspi     = NULL,
	.cs_port  = NULL,
	.cs_pin   = 0,
	.op_ctrl  = BMM150_OPMODE_NORMAL | BMM150_ODR_10HZ,
	.rep_xy   = 0x01U,
	.rep_z    = 0x06U,
};
bmp388_config_t bmp388_conf = {
    .iface    = BMP388_IFACE_SPI,
    .hspi     = &hspi1,
    .cs_port  = SPI1_CS1_GPIO_Port,
    .cs_pin   = SPI1_CS1_Pin,
    .prs_cfg  = BMP388_ODR_50HZ | BMP388_OSR_x8,
    .tmp_cfg  = BMP388_ODR_50HZ | BMP388_OSR_x1,
    .mode     = BMP388_MODE_NORMAL,
    .sea_level_hpa = 1013.25f,
};
icm42688p_config_t icm42688p_conf = {
    .iface         = ICM42688P_IFACE_SPI,
    .hspi          = &hspi2,
    .cs_port       = SPI2_CS1_GPIO_Port,
    .cs_pin        = SPI2_CS1_Pin,
    .hi2c          = NULL,
    .i2c_addr      = 0,
    .gyro_config  = ICM42688P_GYRO_FS_500DPS  | ICM42688P_ODR_1760HZ,
    .accel_config = ICM42688P_ACCEL_FS_8G     | ICM42688P_ODR_1760HZ,
    .acc_scale     = ICM42688P_ACC_SCALE_8G,
    .gyro_scale    = ICM42688P_GYRO_SCALE_500DPS,
};
ina226_config_t ina226_conf = {
	.hi2c          = &hi2c1,
	.i2c_addr      = INA226_I2C_ADDR(0, 0),
	.config_reg    = (INA226_AVG_1 | INA226_VBUS_CT_140US | INA226_VSH_CT_140US | INA226_MODE_SHUNT_BUS_CONT),
	.current_lsb_A = 0.001f,
	.r_shunt_ohm   = 0.002f
};
w25q128_config_t w25q128_conf = {
	.hspi    = &hspi1,
	.cs_port = SPI1_CS2_GPIO_Port,
	.cs_pin  = SPI1_CS2_Pin
};
com_config_t com_conf = {
	.com_method = COM_LORA,
	.m0m1_pin = GPIO_PIN_3,
	.m0m1_port = GPIOB,
	.uart    = &huart2,
	.receive_buf = com_receive_buf,
	.transmit_buf = com_transmit_buf,
	.timeout = 1000,
};
signal_config_t signal_conf = {
	.led_port = GPIOC,
	.led_pin = GPIO_PIN_13,
	.buzzer_htim = &htim1,
	.buzzer_channel = TIM_CHANNEL_3,
};
#endif // DRIVER CONFIG

/* USER CODE END PV */

void SystemClock_Config(void);
static void MPU_Config(void);
void MX_FREERTOS_Init(void);
/* USER CODE BEGIN 0 */
static uint32_t g_log_field_mask = LOG_MASK_ALL;

static uint16_t flight_log_serialize(uint8_t *buf, const flight_log_t *log, uint32_t mask) {
	uint16_t idx = 0;
	memcpy(&buf[idx], &mask, 4); idx += 4;
	memcpy(&buf[idx], &log->timestamp_ms, 4); idx += 4;
	buf[idx++] = log->drone_state;

	if (mask & LOG_FIELD_ACCEL)   { memcpy(&buf[idx], &log->accel, sizeof(FusionVector)); idx += sizeof(FusionVector); }
	if (mask & LOG_FIELD_GYRO)    { memcpy(&buf[idx], &log->gyro,  sizeof(FusionVector)); idx += sizeof(FusionVector); }
	if (mask & LOG_FIELD_MAG)     { memcpy(&buf[idx], &log->mag,   sizeof(FusionVector)); idx += sizeof(FusionVector); }
	if (mask & LOG_FIELD_BARO)    { memcpy(&buf[idx], &log->baro_altitude_m, 4); idx += 4; }
	if (mask & LOG_FIELD_TOF)     { memcpy(&buf[idx], &log->tof_altitude_m,  4); idx += 4; }
	if (mask & LOG_FIELD_FLOW)    { memcpy(&buf[idx], &log->flow_dx, 4); idx += 4;
	                                 memcpy(&buf[idx], &log->flow_dy, 4); idx += 4; }
	if (mask & LOG_FIELD_VOLTAGE) { memcpy(&buf[idx], &log->voltage, 4); idx += 4; }
	if (mask & LOG_FIELD_ORI) {
		memcpy(&buf[idx], &log->rx, 4); idx += 4;
		memcpy(&buf[idx], &log->ry, 4); idx += 4;
		memcpy(&buf[idx], &log->rz, 4); idx += 4;
	}
	if (mask & LOG_FIELD_POS) {
		memcpy(&buf[idx], &log->pos_x, 4); idx += 4;
		memcpy(&buf[idx], &log->pos_y, 4); idx += 4;
		memcpy(&buf[idx], &log->pos_z, 4); idx += 4;
	}
	if (mask & LOG_FIELD_POS_P)   { memcpy(&buf[idx], &log->pos_p_out_x, 4); idx += 4;
	                                 memcpy(&buf[idx], &log->pos_p_out_y, 4); idx += 4; }
	if (mask & LOG_FIELD_VEL_PID) { memcpy(&buf[idx], &log->vel_pid_out_x, 4); idx += 4;
	                                 memcpy(&buf[idx], &log->vel_pid_out_y, 4); idx += 4; }
	if (mask & LOG_FIELD_LQR)     { memcpy(&buf[idx], log->lqr_u, sizeof(log->lqr_u)); idx += sizeof(log->lqr_u); }
	if (mask & LOG_FIELD_SERVO)   { memcpy(&buf[idx], &log->servo_x, 4); idx += 4;
	                                 memcpy(&buf[idx], &log->servo_y, 4); idx += 4; }
	if (mask & LOG_FIELD_MOTOR)   { memcpy(&buf[idx], &log->motor1, 4); idx += 4;
	                                 memcpy(&buf[idx], &log->motor2, 4); idx += 4; }

	return idx;
}

/* Returns false if this record slot is erased/unwritten flash (end of valid
 * data in this page). Otherwise populates *out (fields absent from this
 * record's own mask are left zeroed) and *record_len (bytes consumed). */
static bool flight_log_deserialize(const uint8_t *buf, uint16_t buf_remaining, flight_log_t *out, uint16_t *record_len) {
	if (buf_remaining < 9) return false;

	uint32_t mask;
	memcpy(&mask, &buf[0], 4);
	if (mask == LOG_MASK_ERASED) return false;

	memset(out, 0, sizeof(*out));
	uint16_t idx = 4;
	memcpy(&out->timestamp_ms, &buf[idx], 4); idx += 4;
	out->drone_state = buf[idx++];

	if (mask & LOG_FIELD_ACCEL) { memcpy(&out->accel, &buf[idx], sizeof(FusionVector)); idx += sizeof(FusionVector); }
	if (mask & LOG_FIELD_GYRO)  { memcpy(&out->gyro,  &buf[idx], sizeof(FusionVector)); idx += sizeof(FusionVector); }
	if (mask & LOG_FIELD_MAG)   { memcpy(&out->mag,   &buf[idx], sizeof(FusionVector)); idx += sizeof(FusionVector); }
	if (mask & LOG_FIELD_BARO)  { memcpy(&out->baro_altitude_m, &buf[idx], 4); idx += 4; }
	if (mask & LOG_FIELD_TOF)   { memcpy(&out->tof_altitude_m,  &buf[idx], 4); idx += 4; }
	if (mask & LOG_FIELD_FLOW)  { memcpy(&out->flow_dx, &buf[idx], 4); idx += 4;
	                               memcpy(&out->flow_dy, &buf[idx], 4); idx += 4; }
	if (mask & LOG_FIELD_VOLTAGE) { memcpy(&out->voltage, &buf[idx], 4); idx += 4; }
	if (mask & LOG_FIELD_ORI) {
		memcpy(&out->rx, &buf[idx], 4); idx += 4;
		memcpy(&out->ry, &buf[idx], 4); idx += 4;
		memcpy(&out->rz, &buf[idx], 4); idx += 4;
	}
	if (mask & LOG_FIELD_POS) {
		memcpy(&out->pos_x, &buf[idx], 4); idx += 4;
		memcpy(&out->pos_y, &buf[idx], 4); idx += 4;
		memcpy(&out->pos_z, &buf[idx], 4); idx += 4;
	}
	if (mask & LOG_FIELD_POS_P)   { memcpy(&out->pos_p_out_x, &buf[idx], 4); idx += 4;
	                                 memcpy(&out->pos_p_out_y, &buf[idx], 4); idx += 4; }
	if (mask & LOG_FIELD_VEL_PID) { memcpy(&out->vel_pid_out_x, &buf[idx], 4); idx += 4;
	                                 memcpy(&out->vel_pid_out_y, &buf[idx], 4); idx += 4; }
	if (mask & LOG_FIELD_LQR)     { memcpy(out->lqr_u, &buf[idx], sizeof(out->lqr_u)); idx += sizeof(out->lqr_u); }
	if (mask & LOG_FIELD_SERVO)   { memcpy(&out->servo_x, &buf[idx], 4); idx += 4;
	                                 memcpy(&out->servo_y, &buf[idx], 4); idx += 4; }
	if (mask & LOG_FIELD_MOTOR)   { memcpy(&out->motor1, &buf[idx], 4); idx += 4;
	                                 memcpy(&out->motor2, &buf[idx], 4); idx += 4; }

	*record_len = idx;
	return true;
}

void log_to_flash(flight_log_t *log) {
	if (flash_write_address >= flash_max_address) {
		return;
	}

	uint8_t rec_buf[FLIGHT_LOG_MAX_RECORD_SIZE];
	uint16_t rec_len = flight_log_serialize(rec_buf, log, g_log_field_mask);

	if (flash_buf_idx + rec_len > 256) {
		memset(&flash_page_buffer[flash_buf_idx], 0xFF, 256 - flash_buf_idx);

		w25q128_data_t wdata = { .buf = flash_page_buffer, .len = 256 };
		if (w25q128_write_dma(flash_write_address, &wdata, flash_dma_complete_cb) == HAL_OK) {
			osSemaphoreAcquire(flashDmaSemHandle, W25Q128_TIMEOUT_PAGE_PROGRAM_MS);
		}
		w25q128_wait_busy(W25Q128_TIMEOUT_PAGE_PROGRAM_MS);

		flash_write_address += 256;
		flash_buf_idx = 0;

		if (flash_write_address >= flash_max_address) {
			return;
		}
	}

	memcpy(&flash_page_buffer[flash_buf_idx], rec_buf, rec_len);
	flash_buf_idx += rec_len;
}
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
int main(void)
{

  /* MPU Configuration--------------------------------------------------------*/
  MPU_Config();

  /* MCU Configuration--------------------------------------------------------*/

  /* Reset of all peripherals, Initializes the Flash interface and the Systick. */
  HAL_Init();

  /* Configure the system clock */
  SystemClock_Config();

  /* Initialize all configured peripherals */
  MX_GPIO_Init();
  MX_DMA_Init();
  MX_SDMMC1_SD_Init();
  MX_ADC1_Init();
  MX_I2C1_Init();
  MX_SPI1_Init();
  MX_SPI2_Init();
  MX_TIM2_Init();
  MX_TIM3_Init();
  MX_TIM4_Init();
  MX_USART3_UART_Init();
  MX_USART2_UART_Init();
  MX_TIM1_Init();
  MX_FATFS_Init();
  MX_TIM6_Init();
  /* Init scheduler */
  osKernelInitialize();  /* Call init function for freertos objects (in cmsis_os2.c) */
  MX_FREERTOS_Init();

  /* Start scheduler */
  osKernelStart();

  /* We should never get here as control is now taken by the scheduler */

  /* Infinite loop */
  /* USER CODE BEGIN WHILE */
  while (1)
  {
    /* USER CODE END WHILE */

    /* USER CODE BEGIN 3 */
  }
  /* USER CODE END 3 */
}

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
/* USER CODE BEGIN 4 */
void HAL_UART_RxCpltCallback(UART_HandleTypeDef *huart)
{
    if (huart->Instance == USART2) {
        com_rx_callback(&com_conf);
        osSemaphoreRelease(uart2RxSemHandle);
    }
}

void HAL_UART_ErrorCallback(UART_HandleTypeDef *huart)
{
    if (huart->Instance == USART2) {
        __HAL_UART_CLEAR_OREFLAG(huart);
        HAL_UART_Receive_IT(huart, (uint8_t *)&com_conf.rx_byte, 1);
    }
}

void icm_dma_complete_cb(HAL_StatusTypeDef status)
{
    osSemaphoreRelease(icmDmaSemHandle);
}

void pmw_dma_complete_cb(HAL_StatusTypeDef status)
{
    osSemaphoreRelease(pmwDmaSemHandle);
}

void bmm_dma_complete_cb(HAL_StatusTypeDef status)
{
    osSemaphoreRelease(bmmDmaSemHandle);
}

void bmp_dma_complete_cb(HAL_StatusTypeDef status)
{
    osSemaphoreRelease(bmpDmaSemHandle);
}

void ina_dma_complete_cb(HAL_StatusTypeDef status)
{
    osSemaphoreRelease(inaDmaSemHandle);
}

void flash_dma_complete_cb(HAL_StatusTypeDef status)
{
    osSemaphoreRelease(flashDmaSemHandle);
}


void HAL_UART_TxCpltCallback(UART_HandleTypeDef *huart)
{
    if (huart->Instance == USART2) {
        osSemaphoreRelease(uart2TxDmaSemHandle);
    }
}

void HAL_SPI_RxCpltCallback(SPI_HandleTypeDef *hspi)
{
    if (hspi->Instance == SPI2) {
		if (spi2_pending == SPI2_PENDING_ICM)      icm42688p_dma_irq_handler();
		else if (spi2_pending == SPI2_PENDING_PMW) pmw3901_dma_irq_handler();
		spi2_pending = SPI2_PENDING_NONE;
	} else if (hspi->Instance == SPI1) {
		bmp388_dma_irq_handler();
	}
}

void HAL_SPI_TxCpltCallback(SPI_HandleTypeDef *hspi)
{
    if (hspi->Instance == SPI1) {
        w25q128_dma_irq_handler();
    }
}


void HAL_I2C_MasterRxCpltCallback(I2C_HandleTypeDef *hi2c) {
    if (hi2c->Instance == I2C1) {
        if (i2c1_pending == I2C1_PENDING_BMM)       bmm150_dma_irq_handler();
        else if (i2c1_pending == I2C1_PENDING_VL53) osSemaphoreRelease(i2c1DmaSemHandle);
        i2c1_pending = I2C1_PENDING_NONE;
    }
}

void HAL_I2C_MasterTxCpltCallback(I2C_HandleTypeDef *hi2c) {
    if (hi2c->Instance == I2C1 && i2c1_pending == I2C1_PENDING_VL53) {
        osSemaphoreRelease(i2c1DmaSemHandle);
        i2c1_pending = I2C1_PENDING_NONE;
    }
}

void HAL_I2C_MemRxCpltCallback(I2C_HandleTypeDef *hi2c)
{
    if (hi2c->Instance == I2C1) {
        ina226_dma_irq_handler();
    }
}

/* USER CODE END 4 */

 /* MPU Configuration */

void MPU_Config(void)
{
  MPU_Region_InitTypeDef MPU_InitStruct = {0};

  /* Disables the MPU */
  HAL_MPU_Disable();

  /** Initializes and configures the Region and the memory to be protected
  */
  MPU_InitStruct.Enable = MPU_REGION_ENABLE;
  MPU_InitStruct.Number = MPU_REGION_NUMBER0;
  MPU_InitStruct.BaseAddress = 0x0;
  MPU_InitStruct.Size = MPU_REGION_SIZE_4GB;
  MPU_InitStruct.SubRegionDisable = 0x87;
  MPU_InitStruct.TypeExtField = MPU_TEX_LEVEL0;
  MPU_InitStruct.AccessPermission = MPU_REGION_NO_ACCESS;
  MPU_InitStruct.DisableExec = MPU_INSTRUCTION_ACCESS_DISABLE;
  MPU_InitStruct.IsShareable = MPU_ACCESS_SHAREABLE;
  MPU_InitStruct.IsCacheable = MPU_ACCESS_NOT_CACHEABLE;
  MPU_InitStruct.IsBufferable = MPU_ACCESS_NOT_BUFFERABLE;

  HAL_MPU_ConfigRegion(&MPU_InitStruct);
  /* Enables the MPU */
  HAL_MPU_Enable(MPU_PRIVILEGED_DEFAULT);

}

/**
  * @brief  Period elapsed callback in non blocking mode
  * @note   This function is called  when TIM7 interrupt took place, inside
  * HAL_TIM_IRQHandler(). It makes a direct call to HAL_IncTick() to increment
  * a global variable "uwTick" used as application time base.
  * @param  htim : TIM handle
  * @retval None
  */
void HAL_TIM_PeriodElapsedCallback(TIM_HandleTypeDef *htim)
{
  if (htim->Instance == TIM7)
  {
    HAL_IncTick();
  }
  /* USER CODE BEGIN Callback 1 */
  if (htim->Instance == TIM6) { // 100Hz
	  static int div50 = 0, div10 = 0, div1 = 0;
	  uint32_t flags = CONTROL_100HZ_FLAG;

	  if (++div50 >= 2)   { flags |= CONTROL_50HZ_FLAG;   div50 = 0; } // 50Hz
	  if (++div10 >= 10)  { flags |= CONTROL_10HZ_FLAG;  div10 = 0; } // 10Hz
	  if (++div1  >= 100) { flags |= CONTROL_1HZ_FLAG; div1  = 0; } // 1Hz

	  osThreadFlagsSet(controlTaskHandle, flags);
  }
  /* USER CODE END Callback 1 */
}

/**
  * @brief  This function is executed in case of error occurrence.
  * @retval None
  */
void Error_Handler(void)
{
  /* USER CODE BEGIN Error_Handler_Debug */
  /* User can add his own implementation to report the HAL error return state */
  __disable_irq();
  while (1)
  {
  }
  /* USER CODE END Error_Handler_Debug */
}
#ifdef USE_FULL_ASSERT
/**
  * @brief  Reports the name of the source file and the source line number
  *         where the assert_param error has occurred.
  * @param  file: pointer to the source file name
  * @param  line: assert_param error line source number
  * @retval None
  */
void assert_failed(uint8_t *file, uint32_t line)
{
  /* USER CODE BEGIN 6 */
  /* User can add his own implementation to report the file name and line number,
     ex: printf("Wrong parameters value: file %s on line %d\r\n", file, line) */
  /* USER CODE END 6 */
}
#endif /* USE_FULL_ASSERT */

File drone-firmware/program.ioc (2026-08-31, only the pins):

Mcu.UserName=STM32F722RETx
PA0-WKUP.Signal=S_TIM2_CH1_ETR
PA1.Signal=S_TIM2_CH2
PA10.Signal=S_TIM1_CH3
PA11.Signal=USB_OTG_FS_DM
PA12.Signal=USB_OTG_FS_DP
PA13.Signal=SYS_JTMS-SWDIO
PA14.Signal=SYS_JTCK-SWCLK
PA15.Signal=GPIO_Output
PA2.Signal=USART2_TX
PA3.Signal=USART2_RX
PA4.GPIO_Label=SPI1_CS1
PA4.Signal=GPIO_Output
PA5.Signal=SPI1_SCK
PA6.Signal=SPI1_MISO
PA7.Signal=SPI1_MOSI
PA8.Signal=GPIO_Input
PB0.Signal=S_TIM3_CH3
PB1.Signal=S_TIM3_CH4
PB10.Signal=USART3_TX
PB11.Signal=USART3_RX
PB12.GPIO_Label=SPI2_CS1
PB12.Signal=GPIO_Output
PB13.Signal=SPI2_SCK
PB14.Signal=SPI2_MISO
PB15.Signal=SPI2_MOSI
PB2.Signal=GPIO_Input
PB3.Signal=GPIO_Output
PB4.Signal=S_TIM3_CH1
PB5.Signal=S_TIM3_CH2
PB6.Signal=S_TIM4_CH1
PB7.Signal=S_TIM4_CH2
PB8.Signal=I2C1_SCL
PB9.Signal=I2C1_SDA
PC10.Signal=SDMMC1_D2
PC11.Signal=SDMMC1_D3
PC12.Signal=SDMMC1_CK
PC13.Signal=GPIO_Output
PC4.GPIO_Label=SPI1_CS2
PC4.Signal=GPIO_Output
PC6.Signal=GPXTI6
PC7.GPIO_Label=SPI2_CS2
PC7.Signal=GPIO_Output
PC8.Signal=SDMMC1_D0
PC9.Signal=SDMMC1_D1
PD2.Signal=SDMMC1_CMD
PH0-OSC_IN.Signal=RCC_OSC_IN
PH1-OSC_OUT.Signal=RCC_OSC_OUT

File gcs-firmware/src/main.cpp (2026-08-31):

#include <Arduino.h>

#define DEBUG 0

#if DEBUG
  #define DBG_PRINTLN(x) Serial.println(x)
  #define DBG_PRINT(x)   Serial.print(x)
#else
  #define DBG_PRINTLN(x)
  #define DBG_PRINT(x)
#endif

// ============ Joystick pins ============
// Joystick 1: throttle + yaw
#define VRX1 25   // yaw
#define VRY1 33   // throttle
#define SW1  32   // left switch

// Joystick 2: x/y tilt (roll/pitch)
#define VRX2 14   // roll (rx)
#define VRY2 27   // pitch (ry)
#define SW2  26   // right switch

// ============ Tunable parameters ============
const unsigned long HOLD_TIME_MS  = 500;

const unsigned long SEND_INTERVAL = 20;

const float MAX_VEL = 0.5f;
const float RATE_M_PER_SEC   = 0.5f;

// Low-pass filter time constant (seconds) applied to all four joystick
// channels — larger = smoother/more lag, smaller = snappier/noisier.
const float LPF_TAU = 0.05f;

// Deadband, in stick percent (post-mapJoystickF, so range is -100..100).
// Anything inside this band is clamped to exactly 0 so joystick center
// noise / ADC zero-offset never produces a nonzero target angle. Output
// outside the deadband is rescaled back to the full -100..100 range so
// you don't lose usable travel at the stick's outer edge.
const float STICK_DEADBAND = 3.0f;

// Expo blend: 0 = fully linear, 1 = fully cubic. A cubic-heavy blend
// compresses the response near center (fine control for small angles)
// while still reaching full deflection (MAX_VEL) at full stick travel —
// the two curves meet exactly at +-100%, only the shape in between changes.
// This is what makes 5 deg feel as controllable near-center as 2.5 deg did.
const float STICK_EXPO = 0.4f;

// Max rate at which the *target* velocity (velx_ref/vely_ref) is allowed to
// change, regardless of how fast the stick itself moves. This keeps sudden
// stick snaps (or a noisy LoRa/packet glitch) from slamming a step input
// into the velocity PID. pz_ref is already rate-integrated so it doesn't
// need this.
const float VEL_SLEW_MPS_PER_SEC = 40.0f;

// ============ Calibration storage ============
int vrx1_min, vrx1_center, vrx1_max;
int vry1_min, vry1_center, vry1_max;
int vrx2_min, vrx2_center, vrx2_max;
int vry2_min, vry2_center, vry2_max;

// ============ Low-pass filter state ============
struct LPF {
  float value = 0.0f;
  bool  init  = false;
};

LPF lpfX1, lpfY1, lpfX2, lpfY2;

float lpfUpdate(LPF &f, float raw, float dt, float tau) {
  if (!f.init) {
    f.value = raw;
    f.init  = true;
    return f.value;
  }
  float alpha = dt / (tau + dt);   // dt-normalized EMA — stays consistent even if loop rate jitters
  f.value += alpha * (raw - f.value);
  return f.value;
}

// ============ State machine ============
enum FlightState { STATE_IDLE, STATE_ARMED, STATE_FLYING };
FlightState state = STATE_IDLE;

unsigned long bothHoldStart  = 0;
unsigned long leftHoldStart  = 0;
unsigned long rightHoldStart = 0;
bool armFired    = false;
bool launchFired = false;
bool killFired   = false;

float velx_ref = 0.0f;
float vely_ref = 0.0f;
float pz_ref = 0.0f;

unsigned long lastSendTime = 0;
unsigned long lastLoopTime = 0;

int readCenter(int pin) {
  long sum = 0;
  for (int i = 0; i < 50; i++) { sum += analogReadMilliVolts(pin); delay(5); }
  return sum / 50;
}

// Fully floating-point stick mapping. Previously this used the integer
// map() and was also truncated to int by the caller, which quantized the
// stick reading to ~201 discrete levels (coarser still near center, since
// map() truncates internally). That quantized value fed directly into the
// pz_ref rate integration, producing a visibly stepped ramp even though
// the LPF output feeding it was smooth. Manual float lerp below preserves
// the LPF's precision all the way through.
float mapJoystickF(float raw, int minV, int centerV, int maxV) {
  if (raw < centerV) {
    if (centerV == minV) return 0.0f; // guard divide-by-zero from bad calibration
    return (raw - centerV) / (float)(centerV - minV) * 100.0f; // -> [-100, 0]
  } else {
    if (maxV == centerV) return 0.0f;
    return (raw - centerV) / (float)(maxV - centerV) * 100.0f; // -> [0, 100]
  }
}

// Clamps anything inside +-deadband to zero, then rescales the remainder
// so the usable range still spans the full -100..100 output. Without the
// rescale, deadband would just chop off the middle and leave a "dead" gap
// right where fine hover corrections are made.
float applyDeadband(float val, float deadband) {
  float mag = fabsf(val);
  if (mag < deadband) return 0.0f;
  float sign = (val > 0.0f) ? 1.0f : -1.0f;
  return sign * ((mag - deadband) / (100.0f - deadband)) * 100.0f;
}

// Blends linear and cubic response on a -100..100 input, output also
// -100..100. expo=0 -> identity (linear). expo=1 -> pure cube. Cubic
// compresses small inputs (fine control near center) while endpoints
// (+-100) are unchanged either way, so full-stick still means full angle.
float applyExpo(float val, float expo) {
  float x = val / 100.0f;
  float shaped = expo * (x * x * x) + (1.0f - expo) * x;
  return shaped * 100.0f;
}

// Limits how fast `current` is allowed to move toward `target`, in units
// of val/sec. Used on velx_ref/vely_ref since those are recomputed fresh
// from the stick every loop (not integrated), so without this a stick
// snap is a literal step input into the velocity PID.
float slewLimit(float current, float target, float maxRatePerSec, float dt) {
  float maxDelta = maxRatePerSec * dt;
  float delta = target - current;
  if (delta > maxDelta)  delta = maxDelta;
  if (delta < -maxDelta) delta = -maxDelta;
  return current + delta;
}

bool isPressed(int pin) {
  return digitalRead(pin) == LOW;
}

void sendCommand(const String &cmd) {
  Serial2.print(cmd);
  Serial2.print("\r\n");
  DBG_PRINT("[sent to FC] ");
  DBG_PRINTLN(cmd);
}
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

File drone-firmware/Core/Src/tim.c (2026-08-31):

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
/* Includes ------------------------------------------------------------------*/
#include "tim.h"

TIM_HandleTypeDef htim1;
TIM_HandleTypeDef htim2;
TIM_HandleTypeDef htim3;
TIM_HandleTypeDef htim4;
TIM_HandleTypeDef htim6;

/* TIM1 init function */
void MX_TIM1_Init(void)
{

  TIM_MasterConfigTypeDef sMasterConfig = {0};
  TIM_OC_InitTypeDef sConfigOC = {0};
  TIM_BreakDeadTimeConfigTypeDef sBreakDeadTimeConfig = {0};

  htim1.Instance = TIM1;
  htim1.Init.Prescaler = 107;
  htim1.Init.CounterMode = TIM_COUNTERMODE_UP;
  htim1.Init.Period = 19999;
  htim1.Init.ClockDivision = TIM_CLOCKDIVISION_DIV1;
  htim1.Init.RepetitionCounter = 0;
  htim1.Init.AutoReloadPreload = TIM_AUTORELOAD_PRELOAD_DISABLE;
  if (HAL_TIM_PWM_Init(&htim1) != HAL_OK)
  {
    Error_Handler();
  }
  sMasterConfig.MasterOutputTrigger = TIM_TRGO_RESET;
  sMasterConfig.MasterOutputTrigger2 = TIM_TRGO2_RESET;
  sMasterConfig.MasterSlaveMode = TIM_MASTERSLAVEMODE_DISABLE;
  if (HAL_TIMEx_MasterConfigSynchronization(&htim1, &sMasterConfig) != HAL_OK)
  {
    Error_Handler();
  }
  sConfigOC.OCMode = TIM_OCMODE_PWM1;
  sConfigOC.Pulse = 0;
  sConfigOC.OCPolarity = TIM_OCPOLARITY_HIGH;
  sConfigOC.OCNPolarity = TIM_OCNPOLARITY_HIGH;
  sConfigOC.OCFastMode = TIM_OCFAST_DISABLE;
  sConfigOC.OCIdleState = TIM_OCIDLESTATE_RESET;
  sConfigOC.OCNIdleState = TIM_OCNIDLESTATE_RESET;
  if (HAL_TIM_PWM_ConfigChannel(&htim1, &sConfigOC, TIM_CHANNEL_3) != HAL_OK)
  {
    Error_Handler();
  }
  sBreakDeadTimeConfig.OffStateRunMode = TIM_OSSR_DISABLE;
  sBreakDeadTimeConfig.OffStateIDLEMode = TIM_OSSI_DISABLE;
  sBreakDeadTimeConfig.LockLevel = TIM_LOCKLEVEL_OFF;
  sBreakDeadTimeConfig.DeadTime = 0;
  sBreakDeadTimeConfig.BreakState = TIM_BREAK_DISABLE;
  sBreakDeadTimeConfig.BreakPolarity = TIM_BREAKPOLARITY_HIGH;
  sBreakDeadTimeConfig.BreakFilter = 0;
  sBreakDeadTimeConfig.Break2State = TIM_BREAK2_DISABLE;
  sBreakDeadTimeConfig.Break2Polarity = TIM_BREAK2POLARITY_HIGH;
  sBreakDeadTimeConfig.Break2Filter = 0;
  sBreakDeadTimeConfig.AutomaticOutput = TIM_AUTOMATICOUTPUT_DISABLE;
  if (HAL_TIMEx_ConfigBreakDeadTime(&htim1, &sBreakDeadTimeConfig) != HAL_OK)
  {
    Error_Handler();
  }
  HAL_TIM_MspPostInit(&htim1);

}
/* TIM2 init function */
void MX_TIM2_Init(void)
{

  TIM_ClockConfigTypeDef sClockSourceConfig = {0};
  TIM_MasterConfigTypeDef sMasterConfig = {0};
  TIM_OC_InitTypeDef sConfigOC = {0};

  htim2.Instance = TIM2;
  htim2.Init.Prescaler = 107;
  htim2.Init.CounterMode = TIM_COUNTERMODE_UP;
  htim2.Init.Period = 2499;
  htim2.Init.ClockDivision = TIM_CLOCKDIVISION_DIV1;
  htim2.Init.AutoReloadPreload = TIM_AUTORELOAD_PRELOAD_DISABLE;
  if (HAL_TIM_Base_Init(&htim2) != HAL_OK)
  {
    Error_Handler();
  }
  sClockSourceConfig.ClockSource = TIM_CLOCKSOURCE_INTERNAL;
  if (HAL_TIM_ConfigClockSource(&htim2, &sClockSourceConfig) != HAL_OK)
  {
    Error_Handler();
  }
  if (HAL_TIM_PWM_Init(&htim2) != HAL_OK)
  {
    Error_Handler();
  }
  sMasterConfig.MasterOutputTrigger = TIM_TRGO_RESET;
  sMasterConfig.MasterSlaveMode = TIM_MASTERSLAVEMODE_DISABLE;
  if (HAL_TIMEx_MasterConfigSynchronization(&htim2, &sMasterConfig) != HAL_OK)
  {
    Error_Handler();
  }
  sConfigOC.OCMode = TIM_OCMODE_PWM1;
  sConfigOC.Pulse = 0;
  sConfigOC.OCPolarity = TIM_OCPOLARITY_HIGH;
  sConfigOC.OCFastMode = TIM_OCFAST_DISABLE;
  if (HAL_TIM_PWM_ConfigChannel(&htim2, &sConfigOC, TIM_CHANNEL_1) != HAL_OK)
  {
    Error_Handler();
  }
  if (HAL_TIM_PWM_ConfigChannel(&htim2, &sConfigOC, TIM_CHANNEL_2) != HAL_OK)
  {
    Error_Handler();
  }
  HAL_TIM_MspPostInit(&htim2);

}
/* TIM3 init function */
void MX_TIM3_Init(void)
{

  TIM_ClockConfigTypeDef sClockSourceConfig = {0};
  TIM_MasterConfigTypeDef sMasterConfig = {0};
  TIM_OC_InitTypeDef sConfigOC = {0};

  htim3.Instance = TIM3;
  htim3.Init.Prescaler = 107;
  htim3.Init.CounterMode = TIM_COUNTERMODE_UP;
  htim3.Init.Period = 9999;
  htim3.Init.ClockDivision = TIM_CLOCKDIVISION_DIV1;
  htim3.Init.AutoReloadPreload = TIM_AUTORELOAD_PRELOAD_DISABLE;
  if (HAL_TIM_Base_Init(&htim3) != HAL_OK)
  {
    Error_Handler();
  }
  sClockSourceConfig.ClockSource = TIM_CLOCKSOURCE_INTERNAL;
  if (HAL_TIM_ConfigClockSource(&htim3, &sClockSourceConfig) != HAL_OK)
  {
    Error_Handler();
  }
  if (HAL_TIM_PWM_Init(&htim3) != HAL_OK)
  {
    Error_Handler();
  }
  sMasterConfig.MasterOutputTrigger = TIM_TRGO_RESET;
  sMasterConfig.MasterSlaveMode = TIM_MASTERSLAVEMODE_DISABLE;
  if (HAL_TIMEx_MasterConfigSynchronization(&htim3, &sMasterConfig) != HAL_OK)
  {
    Error_Handler();
  }
  sConfigOC.OCMode = TIM_OCMODE_PWM1;
  sConfigOC.Pulse = 0;
  sConfigOC.OCPolarity = TIM_OCPOLARITY_HIGH;
  sConfigOC.OCFastMode = TIM_OCFAST_DISABLE;
  if (HAL_TIM_PWM_ConfigChannel(&htim3, &sConfigOC, TIM_CHANNEL_1) != HAL_OK)
  {
    Error_Handler();
  }
  if (HAL_TIM_PWM_ConfigChannel(&htim3, &sConfigOC, TIM_CHANNEL_2) != HAL_OK)
  {
    Error_Handler();
  }
  if (HAL_TIM_PWM_ConfigChannel(&htim3, &sConfigOC, TIM_CHANNEL_3) != HAL_OK)
  {
    Error_Handler();
  }
  if (HAL_TIM_PWM_ConfigChannel(&htim3, &sConfigOC, TIM_CHANNEL_4) != HAL_OK)
  {
    Error_Handler();
  }
  HAL_TIM_MspPostInit(&htim3);

}
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

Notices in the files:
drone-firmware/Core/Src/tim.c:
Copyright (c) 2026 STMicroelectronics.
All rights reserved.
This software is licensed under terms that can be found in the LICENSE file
